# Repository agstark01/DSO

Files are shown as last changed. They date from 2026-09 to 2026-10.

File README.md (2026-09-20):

# DSO
Making a digital oscilloscope for frequency range upto 500khz and voltage range upto +-10V. Sharing the waveforms via pc communication to project it on gui using USB2.0 1MBps speed
## You can see full schematics in [DSO_1draft.pdf](assessment1/DSO_1draft/DSO_1draft.pdf).

## Hardware Subsystems & Circuit Schematics

### 1. Analog Input & Channel Multiplexing
Routes and selects between analog input channels and attenuation paths to direct the conditioned signal toward the sampling stage.

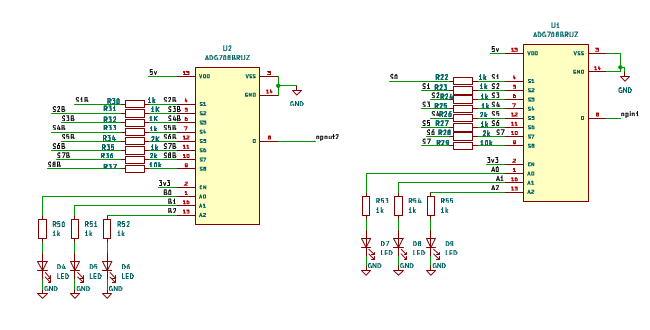
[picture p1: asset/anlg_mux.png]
Analog Multiplexer


---

### 2. Anti-Aliasing Filter
An active low-pass filter stage designed to attenuate high-frequency components above the Nyquist limit, preventing aliasing distortion at the ADC inputs.

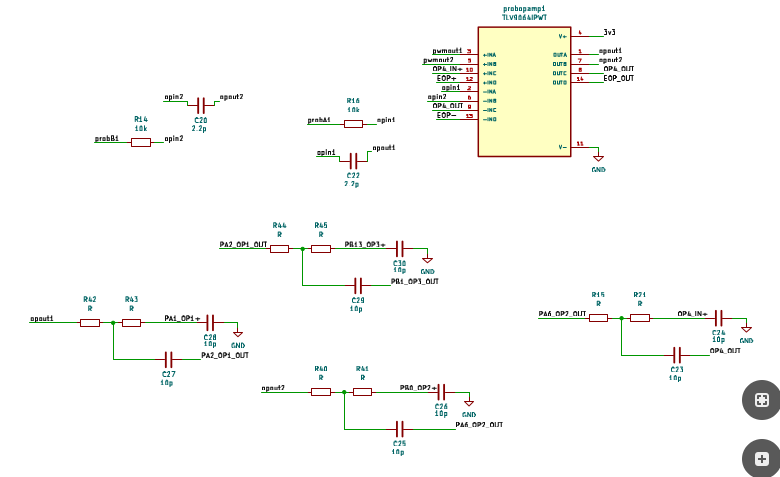
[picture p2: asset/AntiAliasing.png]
Anti-Aliasing Filter


---

### 3. PWM-to-DC Offset Generator
Filters a high-frequency PWM signal from the microcontroller through a low-pass network, producing an adjustable analog DC offset to center and bias bipolar input waveforms within the ADC's 0–3.3V dynamic range.

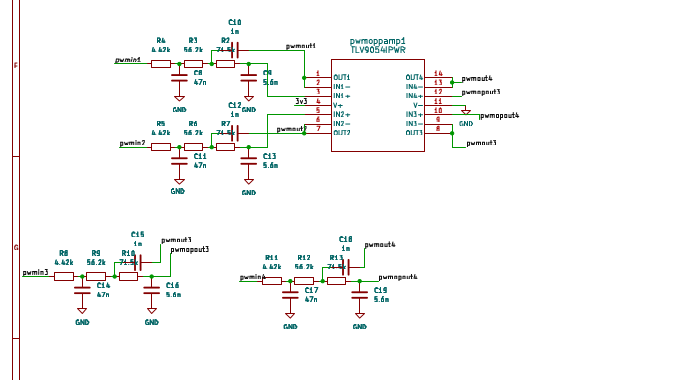
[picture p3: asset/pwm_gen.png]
PWM to DC Offset Stage


---

### 4. Symmetric Dual Supply Generation (±5V)
Generates clean positive (this stage is updated please see pdf) (+5V) and negative (-5V) rails to supply the operational amplifiers, providing the necessary headroom and swing for true bipolar signal conditioning.

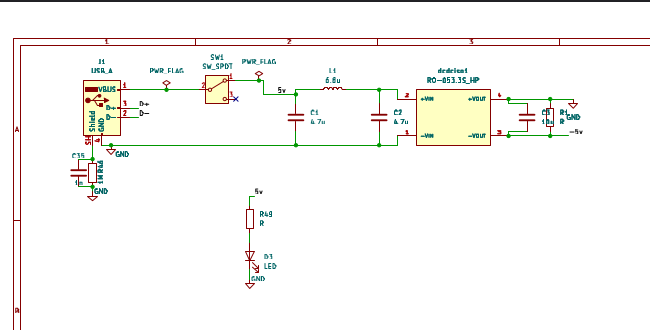
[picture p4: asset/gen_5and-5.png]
±5V Supply Generator


---

### 5. Onboard Function Generator
Generates test signals (e.g., standard 1 kHz square reference or calibration waveforms) for probe compensation, debugging, and self-testing.

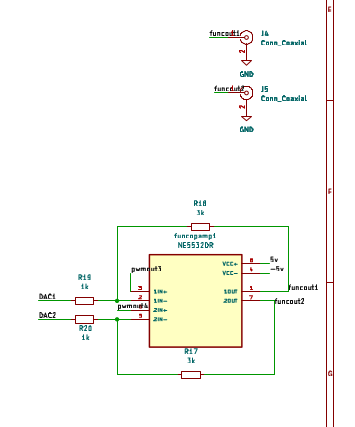
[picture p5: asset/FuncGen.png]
Function Generator


---

### 6. Input Connectors & Channels
Interface connectors (BNC/header pins) for Channel 1 and Channel 2, providing signal entry, grounding, and initial protection.

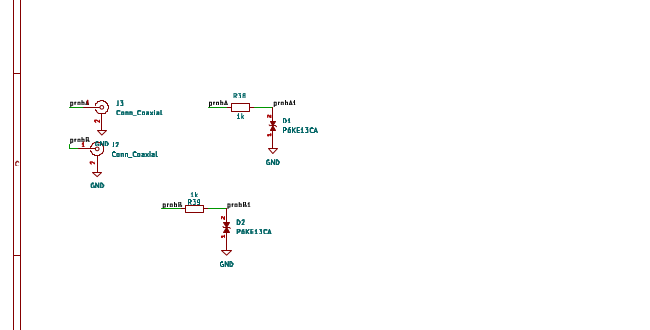
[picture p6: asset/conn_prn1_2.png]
Input Connectors


---

### 7. MCU Programming & Debug Header
Breakout interface (SWD/JTAG and UART/power pins) for flashing firmware to the microcontroller and monitoring real-time telemetry during development.

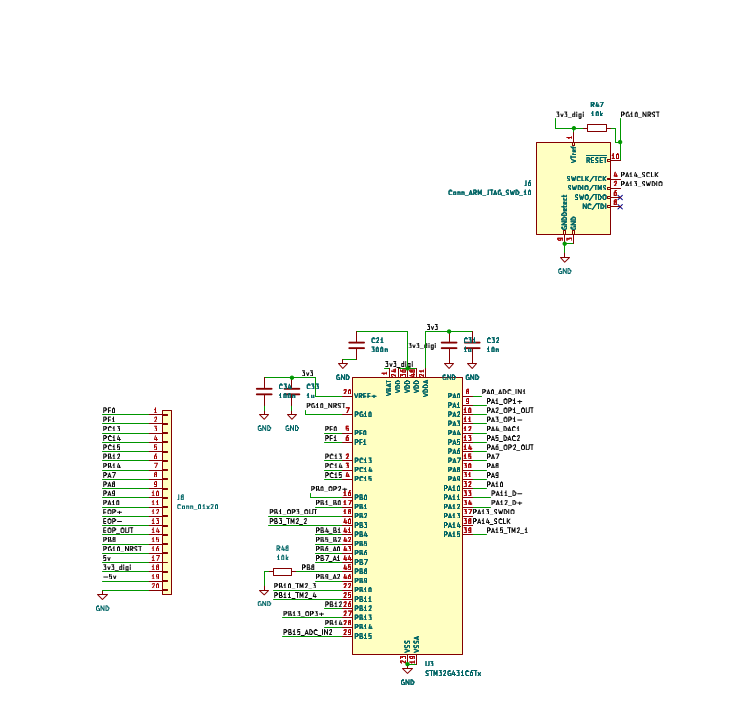
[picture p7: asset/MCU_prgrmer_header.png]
MCU Programmer Header


---

### 8. Net Name & Pin Matching Guide
Reference diagram mapping schematic netlabels, board bus connections, and microcontroller GPIO pinouts across different modules.

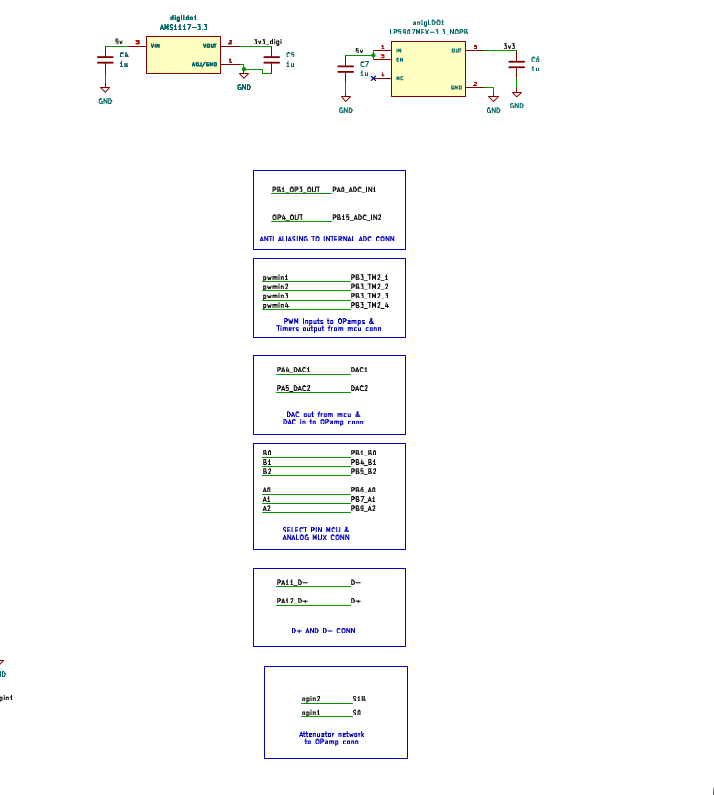
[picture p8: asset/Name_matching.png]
Net Name Matching


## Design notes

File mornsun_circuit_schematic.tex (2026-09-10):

\documentclass[border=20pt]{standalone}
\usepackage[american]{circuitikz}
\begin{document}
\begin{tikzpicture}[scale=1.0, transform shape, thick]

% Power Input
\node[vcc] (vcc_in) at (0,6) {+5V Main};
\node[ground] (gnd_in) at (0,3) {};

% Connect Input
\draw (vcc_in) to[short, -*] (1.5,6) coordinate (in_top);
\draw (gnd_in) to[short, -*] (1.5,3) coordinate (in_bot);
\draw (in_top) to[pC, l=$C_{bulk}$] (in_bot);

% Tap for LDO
\draw (in_top) to[short, -*] (3,6) coordinate (tap_ldo);
\draw (tap_ldo) to[short] (3,8.5) to[short] (4.5,8.5);
\node[draw, minimum width=2.5cm, minimum height=1.5cm, anchor=west] (ldo) at (4.5,8.5) {\shortstack{3.3V LDO\\(e.g., AP7313)}};
\draw (ldo.east) to[short] ++(1.5,0) node[vcc] {3.3V (to DAC)};
\draw (ldo.south) to[short] ++(0,-0.5) node[ground]{};

% Input Filter for DC-DC
\draw (tap_ldo) to[C, l_=$C_1$ $4.7\mu$F, *-*] (3,3);
\draw (3,3) to[short] (in_bot);

\draw (tap_ldo) to[L, l=$L_{DM}$ $6.8\mu$H, -*] (6.5,6) coordinate (dcdc_in);
\draw (3,3) to[short, -*] (6.5,3) coordinate (dcdc_gnd);
\draw (dcdc_in) to[C, l_=$C_2$ $4.7\mu$F, *-*] (dcdc_gnd);

% DC-DC Converter Box
\draw (7.5, 2.5) rectangle (10.5, 6.5);
\node at (9, 4.5) {\shortstack{Mornsun\\B0505S-1WR3}};
\node[anchor=west] at (7.5, 6) {+Vin};
\node[anchor=west] at (7.5, 3) {GND};
\node[anchor=east] at (10.5, 6) {+Vo};
\node[anchor=east] at (10.5, 3) {0V};

\draw (dcdc_in) to[short] (7.5, 6);
\draw (dcdc_gnd) to[short] (7.5, 3);

% Output side
\draw (10.5, 6) to[short, -*] (12, 6) coordinate (vo_plus);
\draw (10.5, 3) to[short, -*] (12, 3) coordinate (vo_minus);

% Grounding +Vo
\draw (vo_plus) to[short] (12, 7.5) node[ground]{System GND};

% Bleeder Resistor
\draw (vo_plus) to[R, l=$R_{bleed}$ $270\Omega$, *-*] (vo_minus);

% Pi Filter on -5V
\draw (vo_minus) to[short, -*] (13.5, 3) coordinate (pi1);
\draw (pi1) to[C, l=$C_3$ $10\mu$F] (13.5, 5) node[ground]{};
\draw (pi1) to[european resistor, l=FB $600\Omega$, -*] (16.5, 3) coordinate (pi2);
\draw (pi2) to[C, l=$C_4$ $10\mu$F+$100$nF] (16.5, 5) node[ground]{};
\draw (pi2) to[short] (18, 3) node[vee] {Clean -5V to Op-Amp};

% Clean 5V Tap for Op-Amp
\draw (tap_ldo) to[short, *-] (3, 0.5) coordinate (op_tap);
\draw (op_tap) to[european resistor, l=FB $600\Omega$, -*] (16.5, 0.5) coordinate (op_vcc);
\draw (op_vcc) to[C, l=$C_{op}$ $10\mu$F+$100$nF] (16.5, -1.5) node[ground]{};
\draw (op_vcc) to[short] (18, 0.5) node[vcc] {Clean +5V to Op-Amp};

\end{tikzpicture}
\end{document}

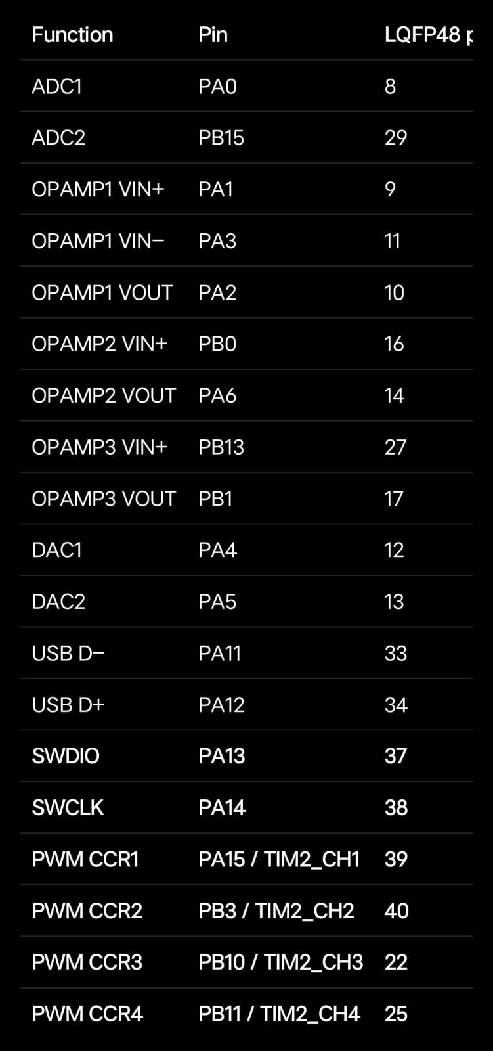
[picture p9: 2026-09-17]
MCUPinConnn.jpeg

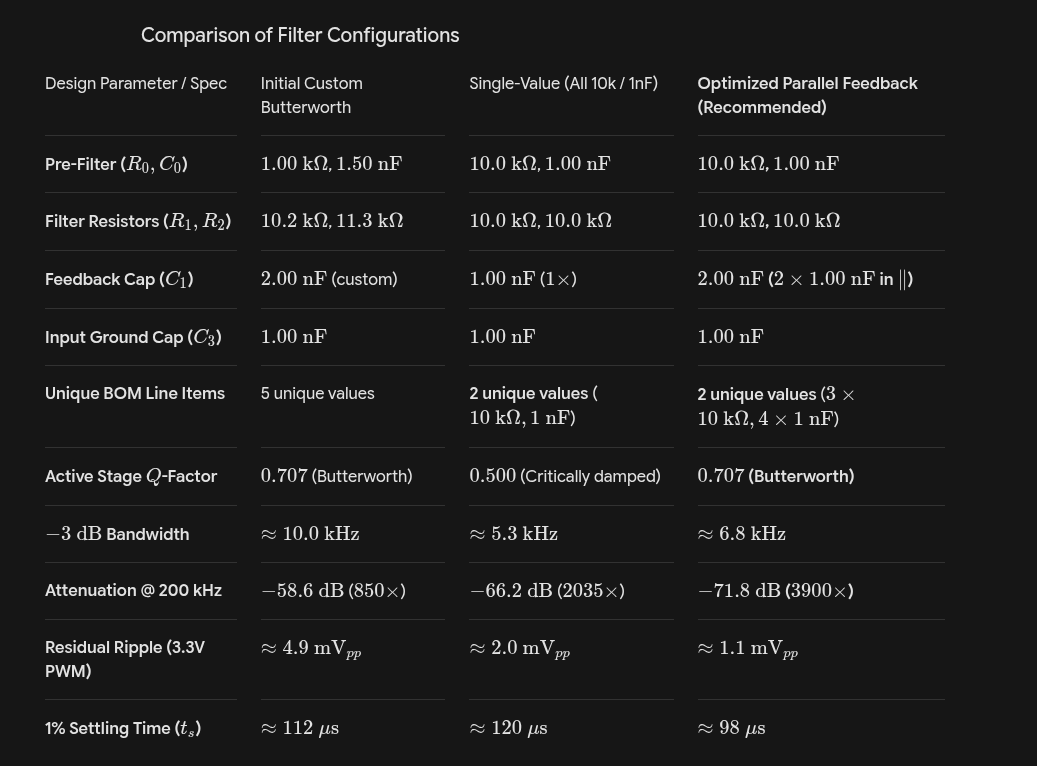
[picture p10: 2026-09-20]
OffsetGen/Pasted image.png

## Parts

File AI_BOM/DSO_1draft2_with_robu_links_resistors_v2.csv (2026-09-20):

Reference | Qty | Value | DNP | Exclude from BOM | Exclude from Board | Exclude from Simulation | Exclude from Position Files | Footprint | Datasheet | Recommended Spec | Robu Purchase Link | Robu Resistor Link | Resistor Alternative
anlgLDO1 | 1 | LP5907MFX-3.3_NOPB |  |  |  |  | ${EXCLUDE_FROM_POS_FILES} | analogLDO:SOT95P280X145-5N
C1,C2 | 2 | 4.7u |  |  |  |  | ${EXCLUDE_FROM_POS_FILES} | Capacitor_SMD:C_1206_3216Metric |  | 10%, X7R, 50 V, 1206 | https://robu.in/product/cl31b475kbhnnne-samsung-electro-mechanics-smd-multilayer-ceramic-capacitor-4-7-%C2%B5f-50-v-1206-pack-of-5/
C3 | 1 | 10u |  |  |  |  | ${EXCLUDE_FROM_POS_FILES} | Capacitor_SMD:C_1206_3216Metric |  | 10%, X7R, 25 V, 1206 | https://robu.in/product/tmk316b7106kl-td-taiyo-yuden-cap-smd-mlcc-10-%C2%B5f-25-v-1206-pack-of-1/
C4,C5,C6,C7,C31,C33 | 6 | 1u |  |  |  |  | ${EXCLUDE_FROM_POS_FILES} | Capacitor_SMD:C_1206_3216Metric |  | 10%, X7R, 25 V, 1206 | https://robu.in/product/c1206c105k3ractu-kemet-smd-multilayer-ceramic-capacitor-1-%C2%B5f-25-v-1206-3216-metric-%C2%B1-10-x7r-c-series-kemet/
C8,C9,C10,C11,C12,C13,C14,C15,C16,C17,C18,C19,C35,C36,C37,C38,C39 | 17 | 1n |  |  |  |  | ${EXCLUDE_FROM_POS_FILES} | Capacitor_SMD:C_1206_3216Metric |  | 1%, C0G/NP0, 50 V, 1206 — Robu exact 1% 1206 listing not found; verify availability | https://robu.in/?s=1nF+1206+C0G+1%25&post_type=product
C20,C22 | 2 | 10p |  |  |  |  | ${EXCLUDE_FROM_POS_FILES} | Capacitor_SMD:C_1206_3216Metric |  | 1%, C0G/NP0, 50 V, 1206 — Robu exact 1% 1206 listing not found; verify availability | https://robu.in/?s=2.2pF+1206+C0G+1%25&post_type=product
C21,C34,C40,C41 | 4 | 100n |  |  |  |  | ${EXCLUDE_FROM_POS_FILES} | Capacitor_SMD:C_1206_3216Metric |  | 10%, X7R, 50 V, 1206 | https://robu.in/?s=1206+100nF+50V+X7R&post_type=product
C23,C29 | 2 | 680p |  |  |  |  | ${EXCLUDE_FROM_POS_FILES} | Capacitor_SMD:C_1206_3216Metric |  | 1%, C0G/NP0, 50 V, 1206 — exact 1% 1206 not found; Robu has 5% 1206 C0G | https://robu.in/product/12065a821jat2a-kyocera-avx-smd-multilayer-ceramic-capacitor-820-pf-50-v-1206-3216-metric-%C2%B1-5-c0g-np0-avx-1206-mlcc/
C24,C25,C26,C27,C28,C30 | 6 | 100p |  |  |  |  | ${EXCLUDE_FROM_POS_FILES} | Capacitor_SMD:C_1206_3216Metric |  | 1%, C0G/NP0, 50 V, 1206 — exact 1% 1206 not found; Robu has 5% 1206 C0G | https://robu.in/product/c1206c101j5gactu-kemet-smd-multilayer-ceramic-capacitor-100-pf-50-v-1206-3216-metric-%C2%B1-5-c0g-np0-c-series-kemet/
C32 | 1 | 10n |  |  |  |  | ${EXCLUDE_FROM_POS_FILES} | Capacitor_SMD:C_1206_3216Metric |  | 1%, C0G/NP0, 50 V, 1206 — Robu exact 1% 1206 listing not found; verify availability | https://robu.in/?s=10nF+1206+C0G+1%25&post_type=product
D1,D2 | 2 | P6KE13CA |  |  |  |  | ${EXCLUDE_FROM_POS_FILES} | TVSdiode:DIOAD1300W80L670D310
D3,D4,D5,D6,D7,D8,D9 | 7 | LED |  |  |  |  | ${EXCLUDE_FROM_POS_FILES} | LED_SMD:LED_1206_3216Metric
dcdciso1 | 1 | RO-053.3S_HP |  |  |  |  | ${EXCLUDE_FROM_POS_FILES} | DCDCisolator:CONV_RO-053.3S_HP
digildo1 | 1 | AMS1117-3.3 |  |  |  |  | ${EXCLUDE_FROM_POS_FILES} | digiLDO:SOT229P700X180-4N
funcopamp1 | 1 | NE5532DR |  |  |  |  | ${EXCLUDE_FROM_POS_FILES} | FuncOPAMP:SOIC127P599X175-8N
J1 | 1 | Conn_01x05 |  |  |  |  | ${EXCLUDE_FROM_POS_FILES} | Connector_PinHeader_2.54mm:PinHeader_1x05_P2.54mm_Vertical
J2,J3,J4,J5 | 4 | Conn_Coaxial |  |  |  |  | ${EXCLUDE_FROM_POS_FILES} | Connector_Coaxial:BNC_Amphenol_B6252HB-NPP3G-50_Horizontal
J7 | 1 | USB_A_Stacked |  |  |  |  | ${EXCLUDE_FROM_POS_FILES} | Connector_USB:USB_A_CUI_UJ2-ADH-TH_Horizontal_Stacked
J8,J9 | 2 | Conn_01x20 |  |  |  |  | ${EXCLUDE_FROM_POS_FILES} | Connector_PinHeader_2.54mm:PinHeader_2x10_P2.54mm_Vertical
L1 | 1 | 6.8u |  |  |  |  | ${EXCLUDE_FROM_POS_FILES} | Inductor_THT:L_Axial_L11.0mm_D4.5mm_P15.24mm_Horizontal_Fastron_MECC
probopamp1 | 1 | TLV9064IPWT |  |  |  |  | ${EXCLUDE_FROM_POS_FILES} | probingopamp:SOP65P640X120-14N
pwmoppamp1 | 1 | TLV9054IPWR |  |  |  |  | ${EXCLUDE_FROM_POS_FILES} | pwmopamp:U_TSSOP_PW_TEX-M | https://www.ti.com/lit/gpn/tlv9054
R1 | 1 | 100 |  |  |  |  | ${EXCLUDE_FROM_POS_FILES} | Resistor_THT:R_Axial_DIN0207_L6.3mm_D2.5mm_P7.62mm_Horizontal |  | 100 Ω, ±1%, THT metal film; keep THT footprint |  | https://robu.in/?s=100+Ohm+0.25W+1%25+Metal+Film+Resistor&post_type=product
R3,R4,R5,R6,R7,R8,R9,R10,R11,R12,R13,R14,R16,R29,R37,R47,R48,R56 | 18 | 10k |  |  |  |  | ${EXCLUDE_FROM_POS_FILES} | Resistor_SMD:R_0805_2012Metric_Pad1.20x1.40mm_HandSolder |  | 10 kΩ, ±1%, 1206, 0.25 W |  | https://robu.in/product/10k-ohm-1-4w-1206-surface-mount-chip-resistor/
R15,R19,R20,R21,R22,R23,R24,R25,R27,R30,R33,R35,R38,R39,R44,R45,R49,R50,R51,R52,R53,R54,R55 | 23 | 1k |  |  |  |  | ${EXCLUDE_FROM_POS_FILES} | Resistor_SMD:R_0805_2012Metric_Pad1.20x1.40mm_HandSolder |  | 1 kΩ, ±1%, 1206, 0.25 W |  | https://robu.in/product/rc1206fr-071kl-yageo-res-thick-film-1206-1k-ohm-1-0-25w1-4w-%C2%B1100ppm-c-pad-smd-t-r/
R17,R18 | 2 | 3k |  |  |  |  | ${EXCLUDE_FROM_POS_FILES} | Resistor_SMD:R_0805_2012Metric_Pad1.20x1.40mm_HandSolder |  | 3.01 kΩ, ±1%, 1206, 0.25 W — near substitute for 3 kΩ (+0.33%) |  | https://robu.in/product/ac1206fr-073k01l-yageo-250mw-3-01k%CF%89-thick-film-200v-%C2%B11-%C2%B1100ppm-%E2%84%83-1206-chip-resistor-surface-mount-rohs/ | 3.01 kΩ
R26,R28,R36,R40,R41,R42,R43 | 7 | 2.2k |  |  |  |  | ${EXCLUDE_FROM_POS_FILES} | Resistor_SMD:R_0805_2012Metric_Pad1.20x1.40mm_HandSolder |  | 2.00 kΩ, ±1%, 1206 preferred; Robu exact listing not verified |  | https://robu.in/?s=2k+1206+1%25+resistor&post_type=product | 2.05 kΩ is the next practical E96-style near-value to check if 2.00 kΩ is unavailable
R31,R32 | 2 | 1K |  |  |  |  | ${EXCLUDE_FROM_POS_FILES} | Resistor_SMD:R_0805_2012Metric_Pad1.20x1.40mm_HandSolder |  | 1 kΩ, ±1%, 1206, 0.25 W |  | https://robu.in/product/rc1206fr-071kl-yageo-res-thick-film-1206-1k-ohm-1-0-25w1-4w-%C2%B1100ppm-c-pad-smd-t-r/
R34 | 1 | 2.2k |  |  |  |  | ${EXCLUDE_FROM_POS_FILES} | Resistor_SMD:R_0805_2012Metric_Pad1.20x1.40mm_HandSolder |  | 2.00 kΩ, ±1%, 1206 preferred; same as 2 kΩ group |  | https://robu.in/?s=2k+1206+1%25+resistor&post_type=product | 2.05 kΩ near alternative to check if exact 2.00 kΩ is unavailable
R46 | 1 | 1M |  |  |  |  | ${EXCLUDE_FROM_POS_FILES} | Resistor_THT:R_Axial_DIN0207_L6.3mm_D2.5mm_P7.62mm_Horizontal |  | 1 MΩ, ±1%, 0.25 W; THT as currently specified |  | https://robu.in/?s=1M+Ohm+0.25W+1%25+Metal+Film+Resistor&post_type=product
SW1,SW2 | 2 | SW_SPDT |  |  |  |  | ${EXCLUDE_FROM_POS_FILES} | Slide_switch:SS-12F17_1P2T
U1,U2 | 2 | ADG708BRUZ |  |  |  |  | ${EXCLUDE_FROM_POS_FILES} | Analog_mux:TSSOP16
U3 | 1 | STM32G431C6Tx |  |  |  |  | ${EXCLUDE_FROM_POS_FILES} | Package_QFP:LQFP-48_7x7mm_P0.5mm | https://www.st.com/resource/en/datasheet/stm32g431c6.pdf

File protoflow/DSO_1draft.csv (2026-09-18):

Reference | Qty | Value | DNP | Exclude from BOM | Exclude from Board | Exclude from Simulation | Exclude from Position Files | Footprint | Datasheet
anlgLDO1 | 1 | LP5907MFX-3.3_NOPB |  |  |  |  | ${EXCLUDE_FROM_POS_FILES} | LP5907MFX-3.3_NOPB:SOT95P280X145-5N
C1,C2 | 2 | 4.7u |  |  |  |  | ${EXCLUDE_FROM_POS_FILES}
C3 | 1 | 10u |  |  |  |  | ${EXCLUDE_FROM_POS_FILES}
C4,C5,C6,C7,C31,C33 | 6 | 1u |  |  |  |  | ${EXCLUDE_FROM_POS_FILES}
C8,C11,C14,C17 | 4 | 47n |  |  |  |  | ${EXCLUDE_FROM_POS_FILES}
C9,C13,C16,C19 | 4 | 5.6n |  |  |  |  | ${EXCLUDE_FROM_POS_FILES}
C10,C12,C15,C18,C35 | 5 | 1n |  |  |  |  | ${EXCLUDE_FROM_POS_FILES}
C20,C22 | 2 | 2.2p |  |  |  |  | ${EXCLUDE_FROM_POS_FILES}
C21 | 1 | 300n |  |  |  |  | ${EXCLUDE_FROM_POS_FILES}
C23,C24,C25,C26,C27,C28,C29,C30 | 8 | 10p |  |  |  |  | ${EXCLUDE_FROM_POS_FILES}
C32 | 1 | 10n |  |  |  |  | ${EXCLUDE_FROM_POS_FILES}
C34 | 1 | 100n |  |  |  |  | ${EXCLUDE_FROM_POS_FILES}
D1,D2 | 2 | P6KE13CA |  |  |  |  | ${EXCLUDE_FROM_POS_FILES} | P6KE13CA:DIOAD1300W80L670D310
D3,D4,D5,D6,D7,D8,D9 | 7 | LED |  |  |  |  | ${EXCLUDE_FROM_POS_FILES}
dcdciso1 | 1 | RO-053.3S_HP |  |  |  |  | ${EXCLUDE_FROM_POS_FILES} | RO-053.3S_HP:CONV_RO-053.3S_HP
digildo1 | 1 | AMS1117-3.3 |  |  |  |  | ${EXCLUDE_FROM_POS_FILES} | AMS1117-3.3:SOT229P700X180-4N
funcopamp1 | 1 | NE5532DR |  |  |  |  | ${EXCLUDE_FROM_POS_FILES} | NE5532DR:SOIC127P599X175-8N
J1 | 1 | USB_A , sym and ftprnt have to chg to double usb |  |  |  |  | ${EXCLUDE_FROM_POS_FILES}
J2,J3,J4,J5 | 4 | Conn_Coaxial (shriniwas comp) |  |  |  |  | ${EXCLUDE_FROM_POS_FILES}
J6 | 1 | Conn_ARM_JTAG_SWD_10 |  |  |  |  | ${EXCLUDE_FROM_POS_FILES} |  | http://infocenter.arm.com/help/topic/com.arm.doc.ddi0314h/DDI0314H_coresight_components_trm.pdf
J8 | 1 | Conn_01x20 |  |  |  |  | ${EXCLUDE_FROM_POS_FILES}
L1 | 1 | 6.8u |  |  |  |  | ${EXCLUDE_FROM_POS_FILES}
probopamp1 | 1 | TLV9064IPWT |  |  |  |  | ${EXCLUDE_FROM_POS_FILES} | TLV9064IPWT:SOP65P640X120-14N
pwmoppamp1 | 1 | TLV9054IPWR |  |  |  |  | ${EXCLUDE_FROM_POS_FILES} | U_TSSOP_PW_TEX | https://www.ti.com/lit/gpn/tlv9054
R1,R15,R21,R40,R41,R42,R43,R44,R45,R49 | 10 | R |  |  |  |  | ${EXCLUDE_FROM_POS_FILES}
R2,R7,R10,R13 | 4 | 71.5k |  |  |  |  | ${EXCLUDE_FROM_POS_FILES}
R3,R6,R9,R12 | 4 | 56.2k |  |  |  |  | ${EXCLUDE_FROM_POS_FILES}
R4,R5,R8,R11 | 4 | 4.42k |  |  |  |  | ${EXCLUDE_FROM_POS_FILES}
R14,R16,R29,R37,R47,R48 | 6 | 10k |  |  |  |  | ${EXCLUDE_FROM_POS_FILES}
R17,R18 | 2 | 3k |  |  |  |  | ${EXCLUDE_FROM_POS_FILES}
R19,R20,R22,R23,R24,R25,R27,R30,R33,R35,R38,R39,R50,R51,R52,R53,R54,R55 | 18 | 1k |  |  |  |  | ${EXCLUDE_FROM_POS_FILES}
R26,R28,R36 | 3 | 2k |  |  |  |  | ${EXCLUDE_FROM_POS_FILES}
R31,R32 | 2 | 1K |  |  |  |  | ${EXCLUDE_FROM_POS_FILES}
R34 | 1 | 2K |  |  |  |  | ${EXCLUDE_FROM_POS_FILES}
R46 | 1 | 1M |  |  |  |  | ${EXCLUDE_FROM_POS_FILES}
SW1 | 1 | SW_SPDT |  |  |  |  | ${EXCLUDE_FROM_POS_FILES}
U1,U2 | 2 | ADG708BRUZ |  |  |  |  | ${EXCLUDE_FROM_POS_FILES} | ADG708BRUZ:TSSOP16
U3 | 2 | STM32G431C6Tx |  |  |  |  | ${EXCLUDE_FROM_POS_FILES} | Package_QFP:LQFP-48_7x7mm_P0.5mm | https://www.st.com/resource/en/datasheet/stm32g431c6.pdf

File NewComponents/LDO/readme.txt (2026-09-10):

# making this folder for saving all the digital and analog LDO files

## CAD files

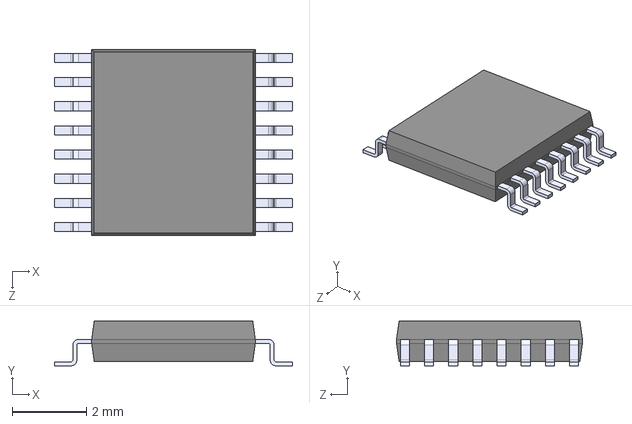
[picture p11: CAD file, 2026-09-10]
NewComponents/Analog_MUX/ADG708BRUZ/ADG708BRUZ.step
6.40 x 1.20 x 5.00 mm

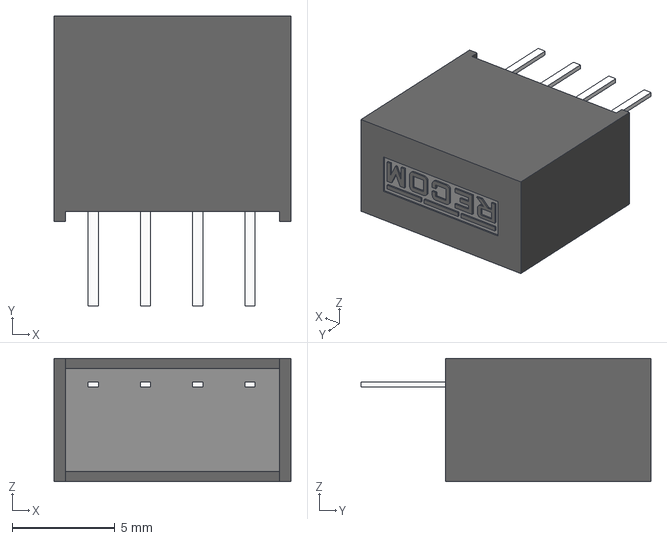
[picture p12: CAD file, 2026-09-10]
NewComponents/charge_pump/isolated/RO-053.3S_HP/RO-053.3S_HP.step
11.5 x 14.1 x 6.00 mm

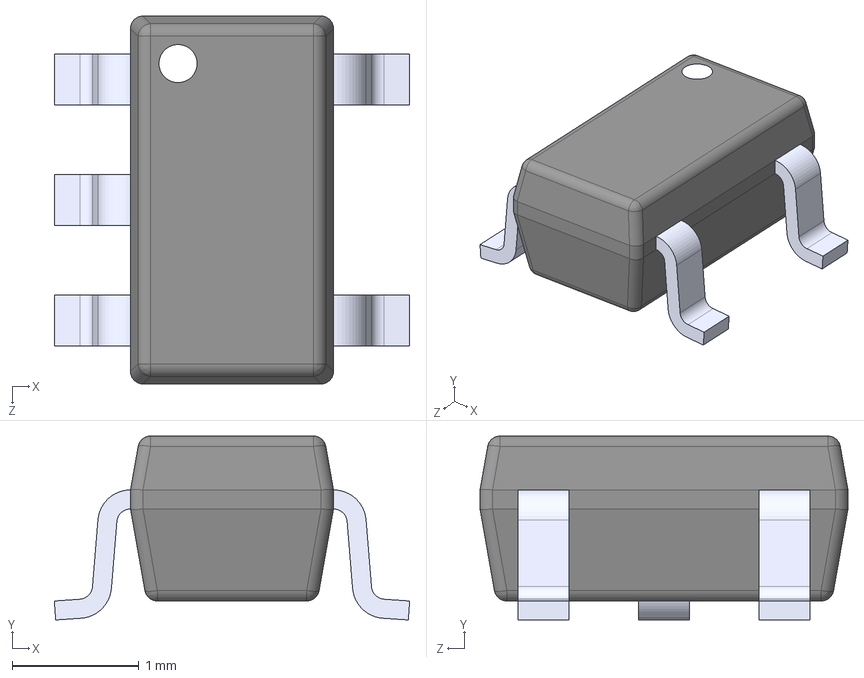
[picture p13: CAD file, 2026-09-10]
NewComponents/LDO/Analog LDO/LP5907MFX-3.3_NOPB/LP5907MFX-3.3_NOPB.step
2.80 x 1.45 x 2.90 mm

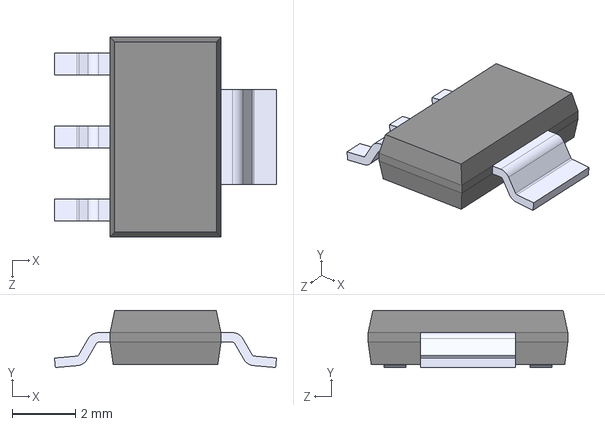
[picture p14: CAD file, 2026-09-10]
NewComponents/LDO/Digital LDO/AMS1117-3.3/AMS1117-3.3.step
7.00 x 1.80 x 6.30 mm

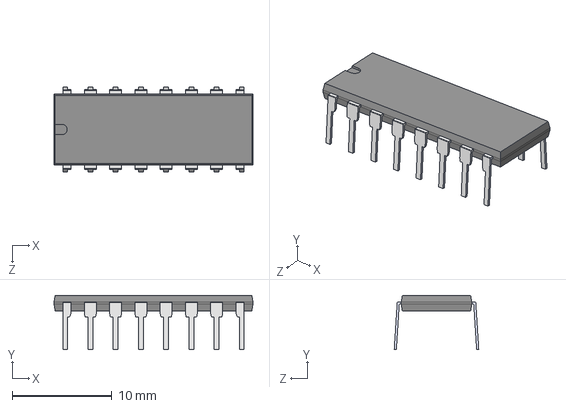
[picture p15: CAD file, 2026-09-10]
NewComponents/LIB_HCF4051BE/HCF4051BE/3D/HCF4051BE.stp
20.0 x 5.45 x 8.50 mm

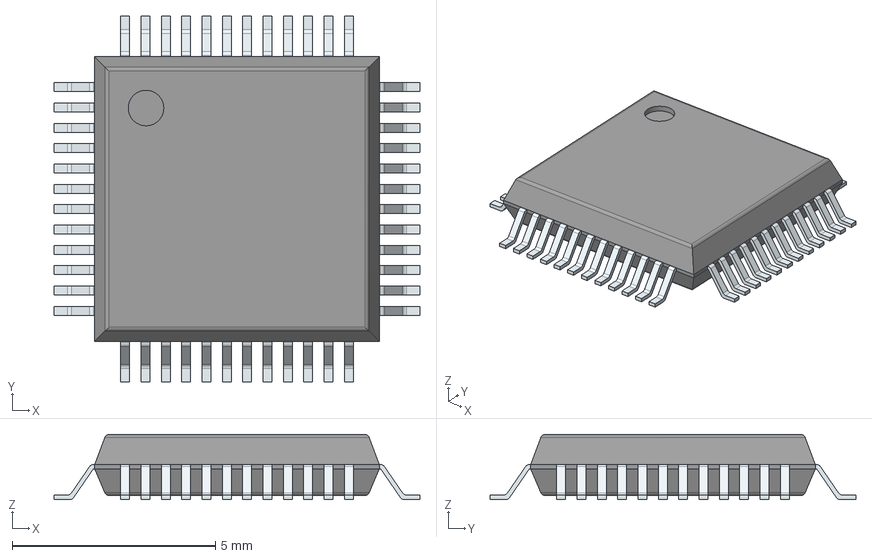
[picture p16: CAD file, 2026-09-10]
NewComponents/LIB_STM32G431C6T6/STM32G431C6T6/3D/STM32G431C6T6.stp
9.00 x 9.00 x 1.60 mm
PinsArrayLR
PinsArrayTB

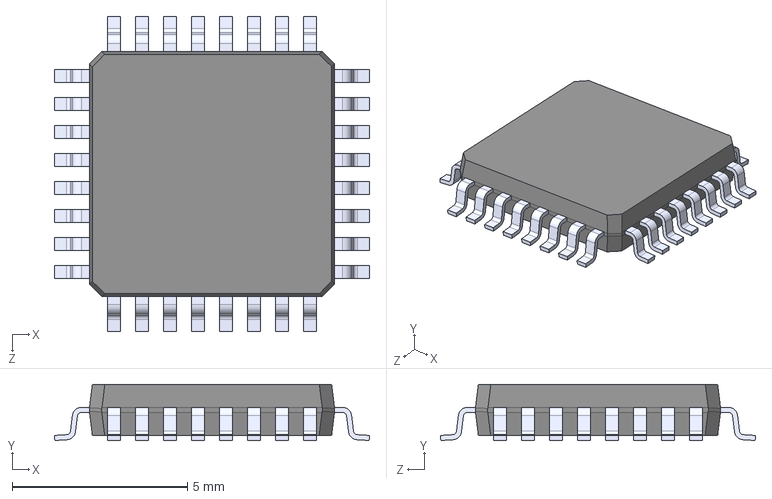
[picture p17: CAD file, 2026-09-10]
NewComponents/MCU/STM32G431KBT6/STM32G431KBT6.step
9.00 x 1.60 x 9.00 mm

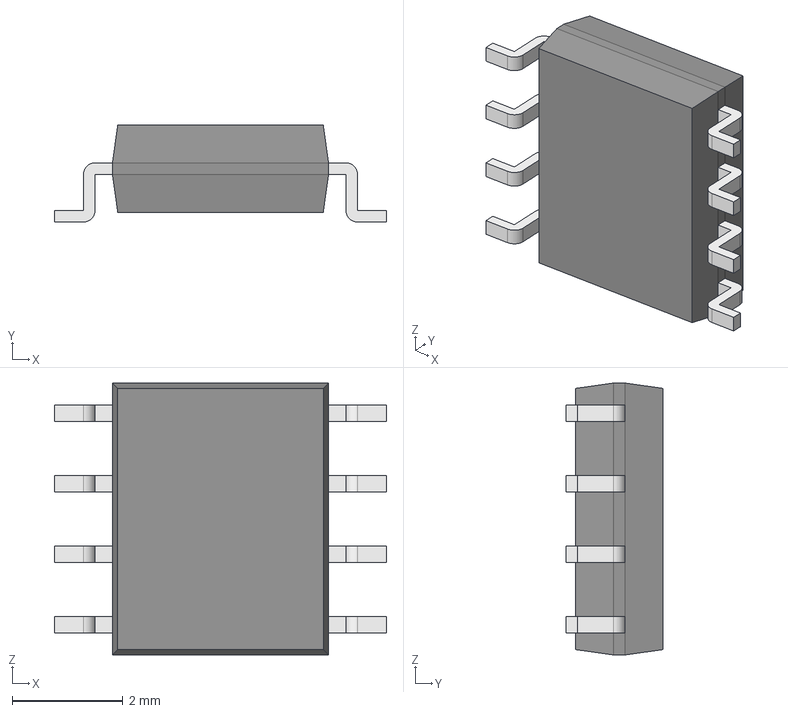
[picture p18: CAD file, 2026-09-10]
NewComponents/quad_oamp/latest_funcgen/NE5532DR/NE5532DR.step
5.99 x 1.75 x 4.91 mm
Body001 (Mirror #1) x 4
XY-plane x 12
X-axis x 12

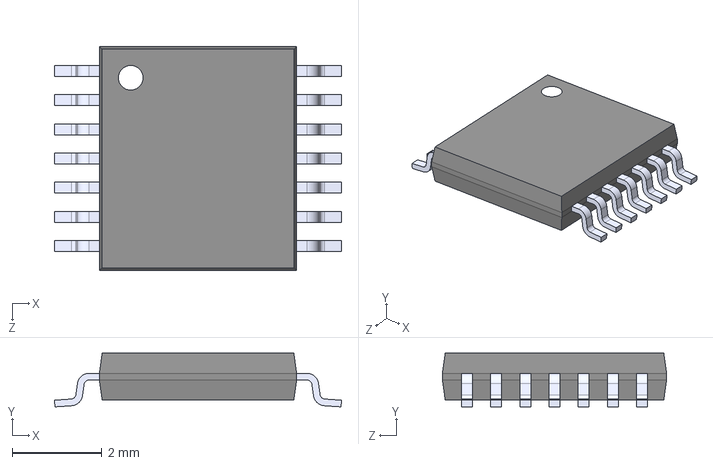
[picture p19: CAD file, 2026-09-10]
NewComponents/quad_oamp/latest_probingpath/TLV9064IPWT/TLV9064IPWT.step
6.40 x 1.20 x 5.00 mm

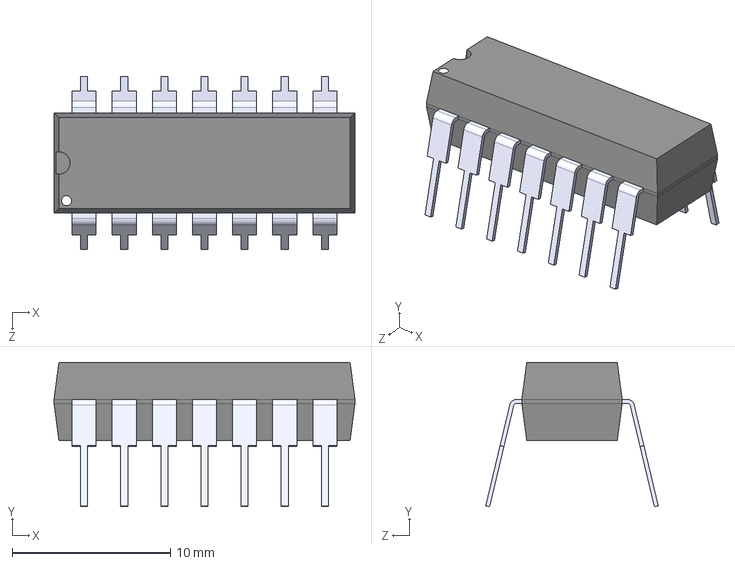
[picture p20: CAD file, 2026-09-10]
NewComponents/quad_oamp/MCP6024-I_P/MCP6024-I_P.step
19.1 x 9.14 x 10.9 mm

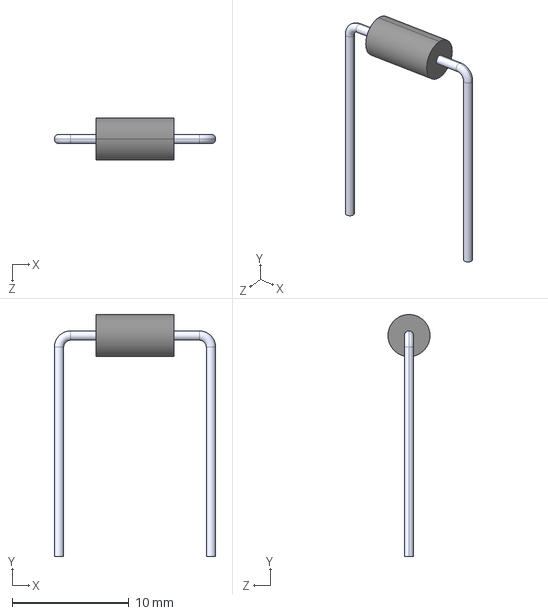
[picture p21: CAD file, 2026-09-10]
NewComponents/TVS/P6KE13CA/P6KE13CA.step
13.8 x 20.7 x 3.60 mm

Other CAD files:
NewComponents/LIB_HCF4051BE/HCF4051BE/Allegro/dip850w50p254l2000h510q16n.psm
NewComponents/LIB_HCF4051BE/HCF4051BE/DEHDL/hcf4051be/chips/chips.prt
NewComponents/LIB_STM32G431C6T6/STM32G431C6T6/Allegro/qfp50p900x900x160-48n.psm
NewComponents/LIB_STM32G431C6T6/STM32G431C6T6/DEHDL/stm32g431c6t6/chips/chips.prt

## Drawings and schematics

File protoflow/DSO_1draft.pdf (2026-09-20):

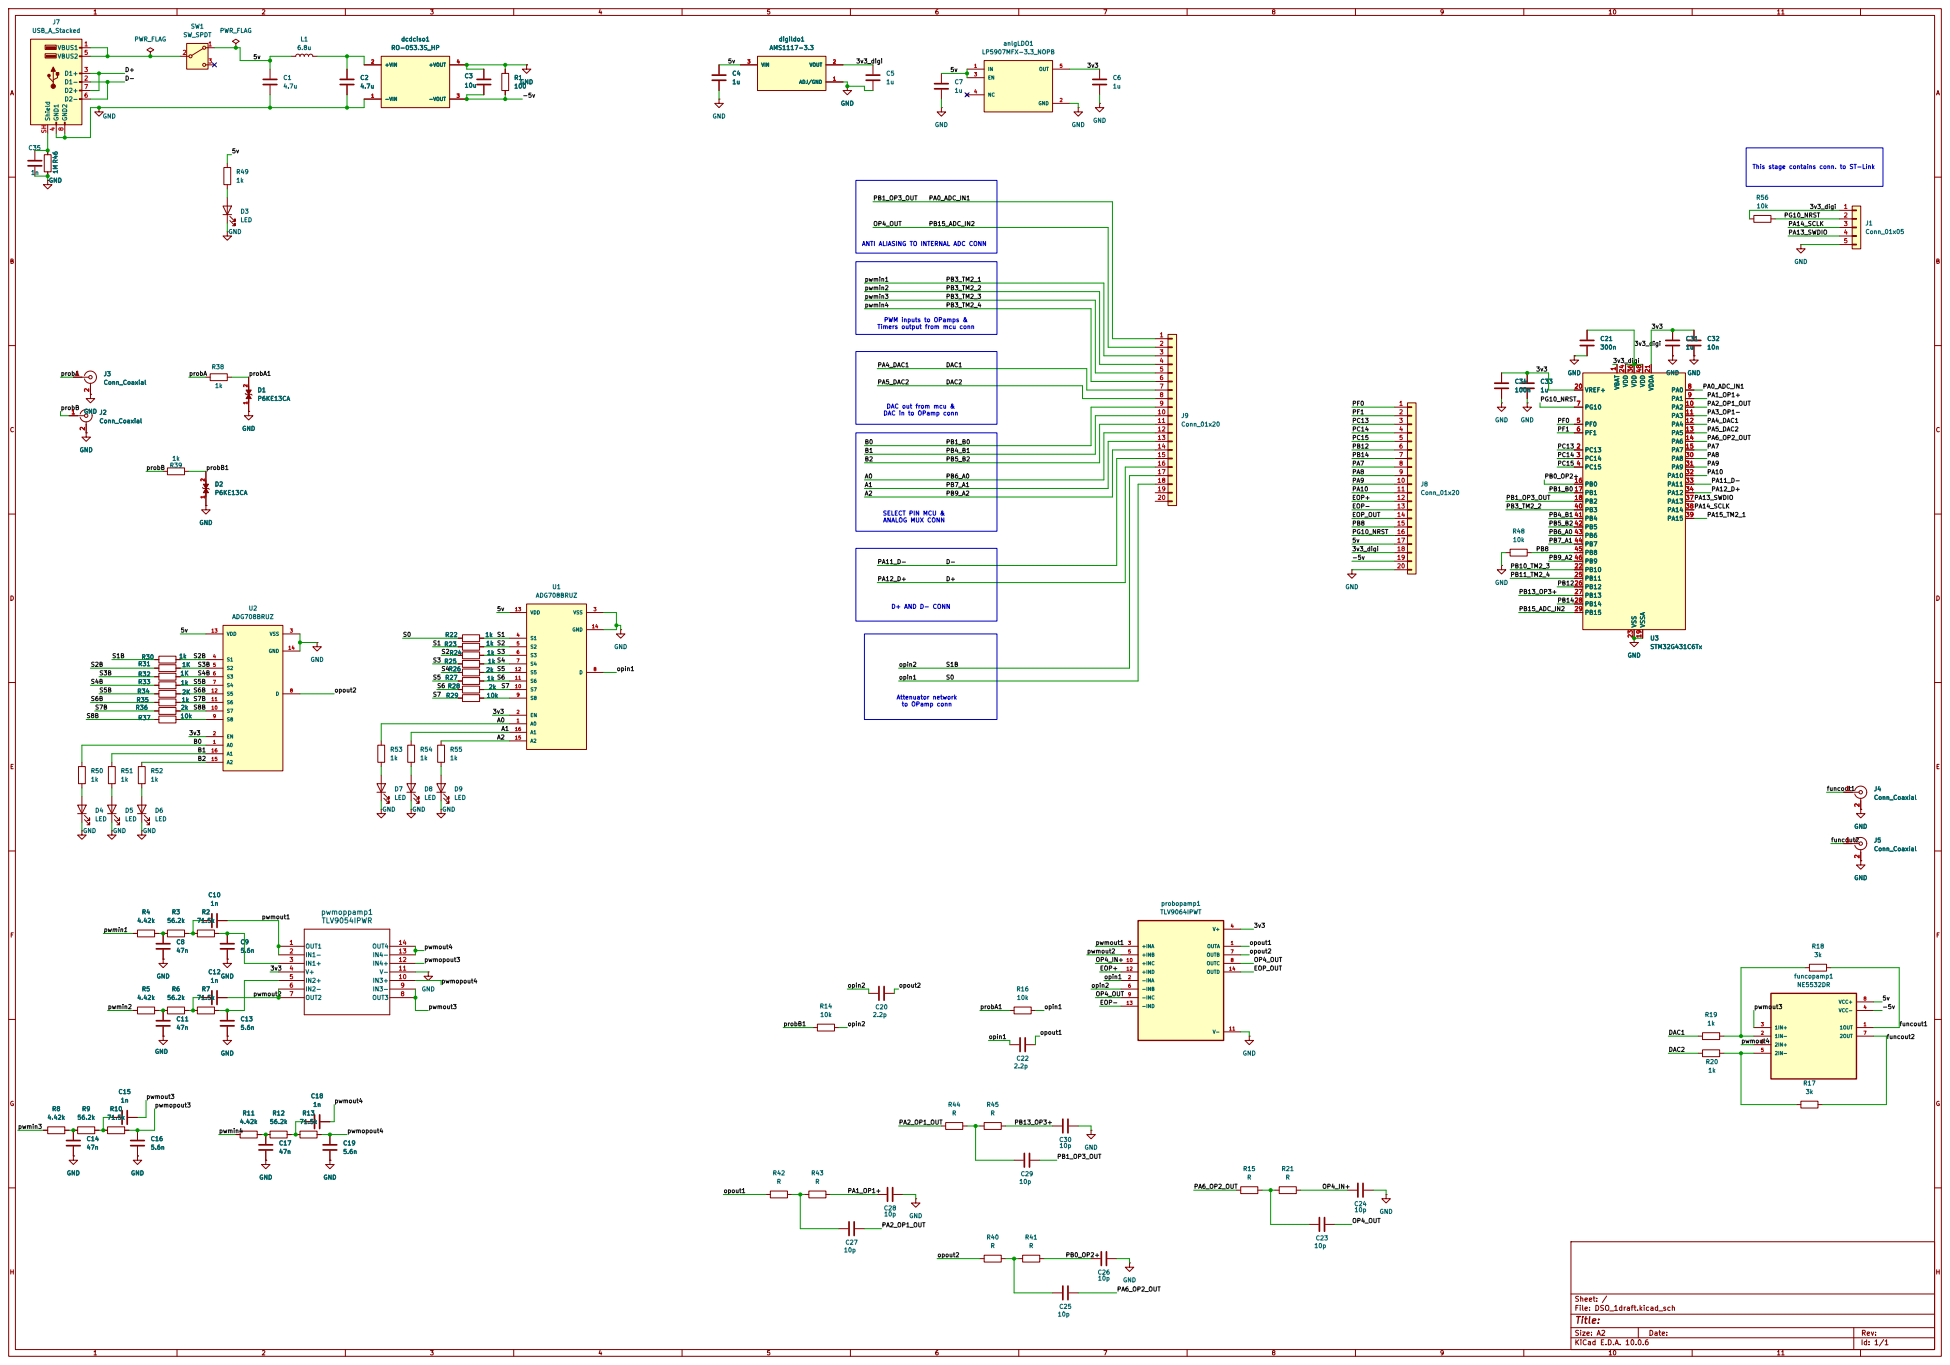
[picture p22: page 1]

This stage contains conn. to ST-Link D+ AND D- CONN

ANTI ALIASING TO INTERNAL ADC CONN

PB9_A2 PB7_A1 PWM inputs to OPamps &
Timers output from mcu conn
PB6_A0 PB5_B2 PB1_B0 PB4_B1 PB7_A1 PB9_A2 DAC1 D+

DAC out from mcu &
DAC in to OPamp conn

Size: A2 | Rev:
KiCad E.D.A. 10.0.6 | Id: 1/1

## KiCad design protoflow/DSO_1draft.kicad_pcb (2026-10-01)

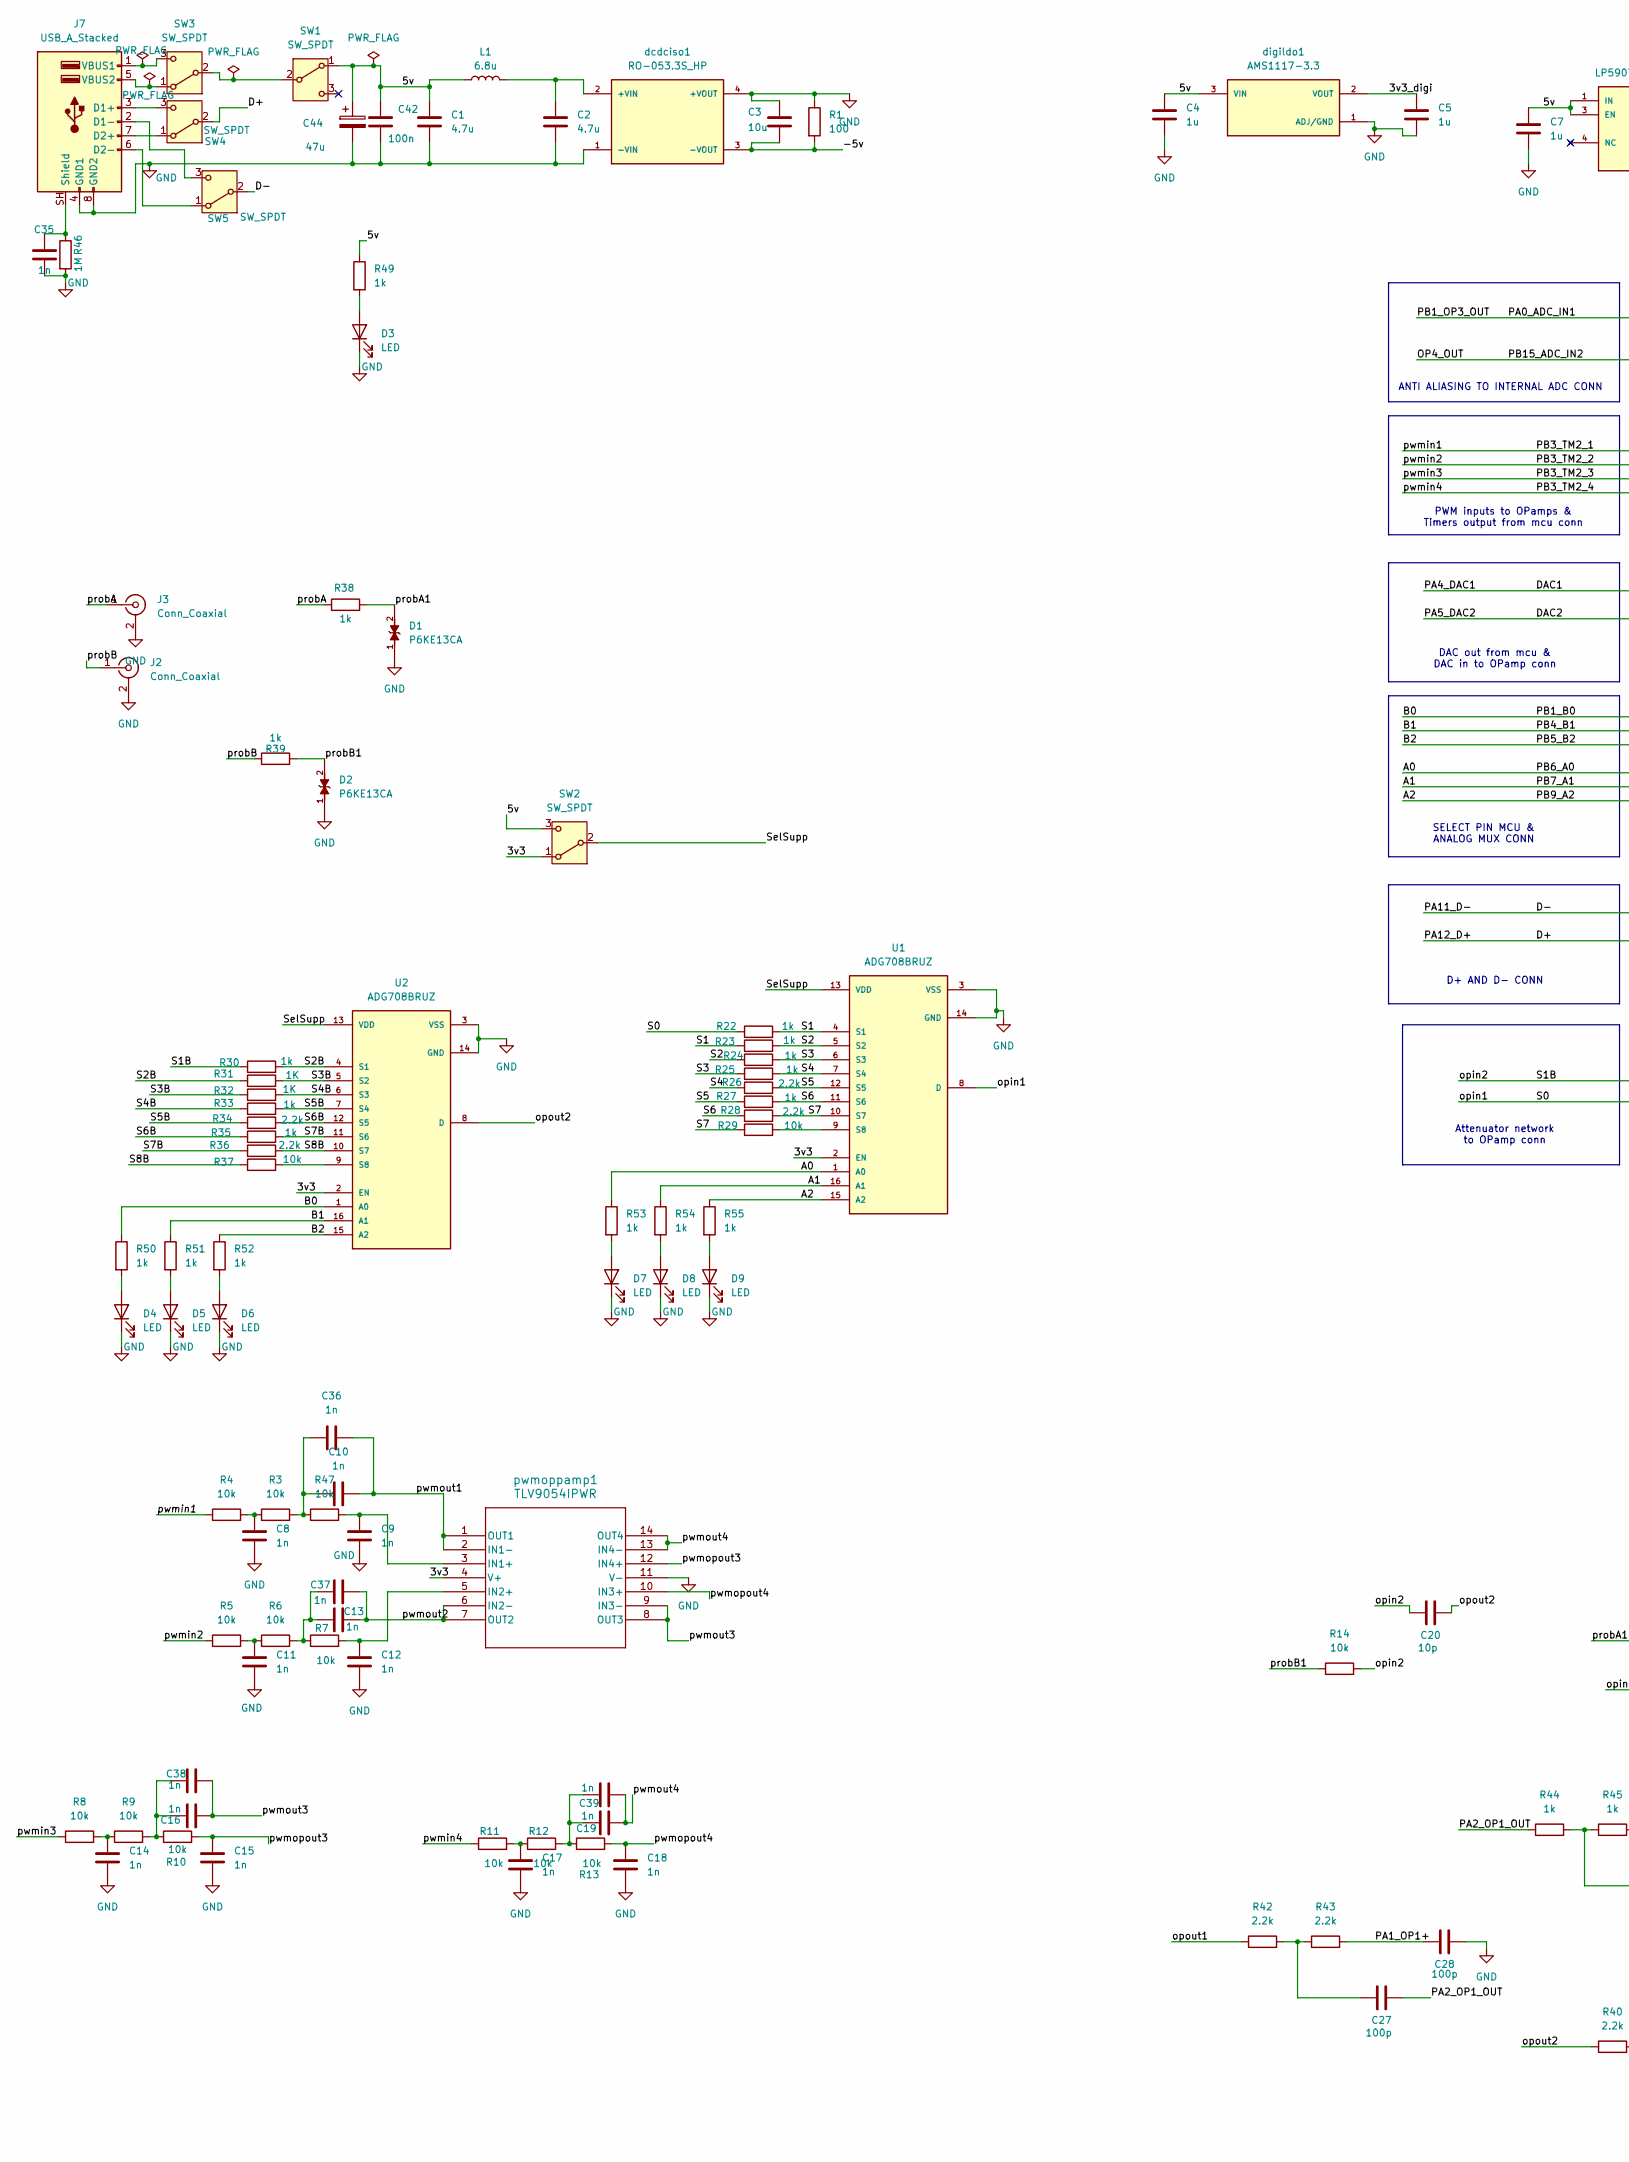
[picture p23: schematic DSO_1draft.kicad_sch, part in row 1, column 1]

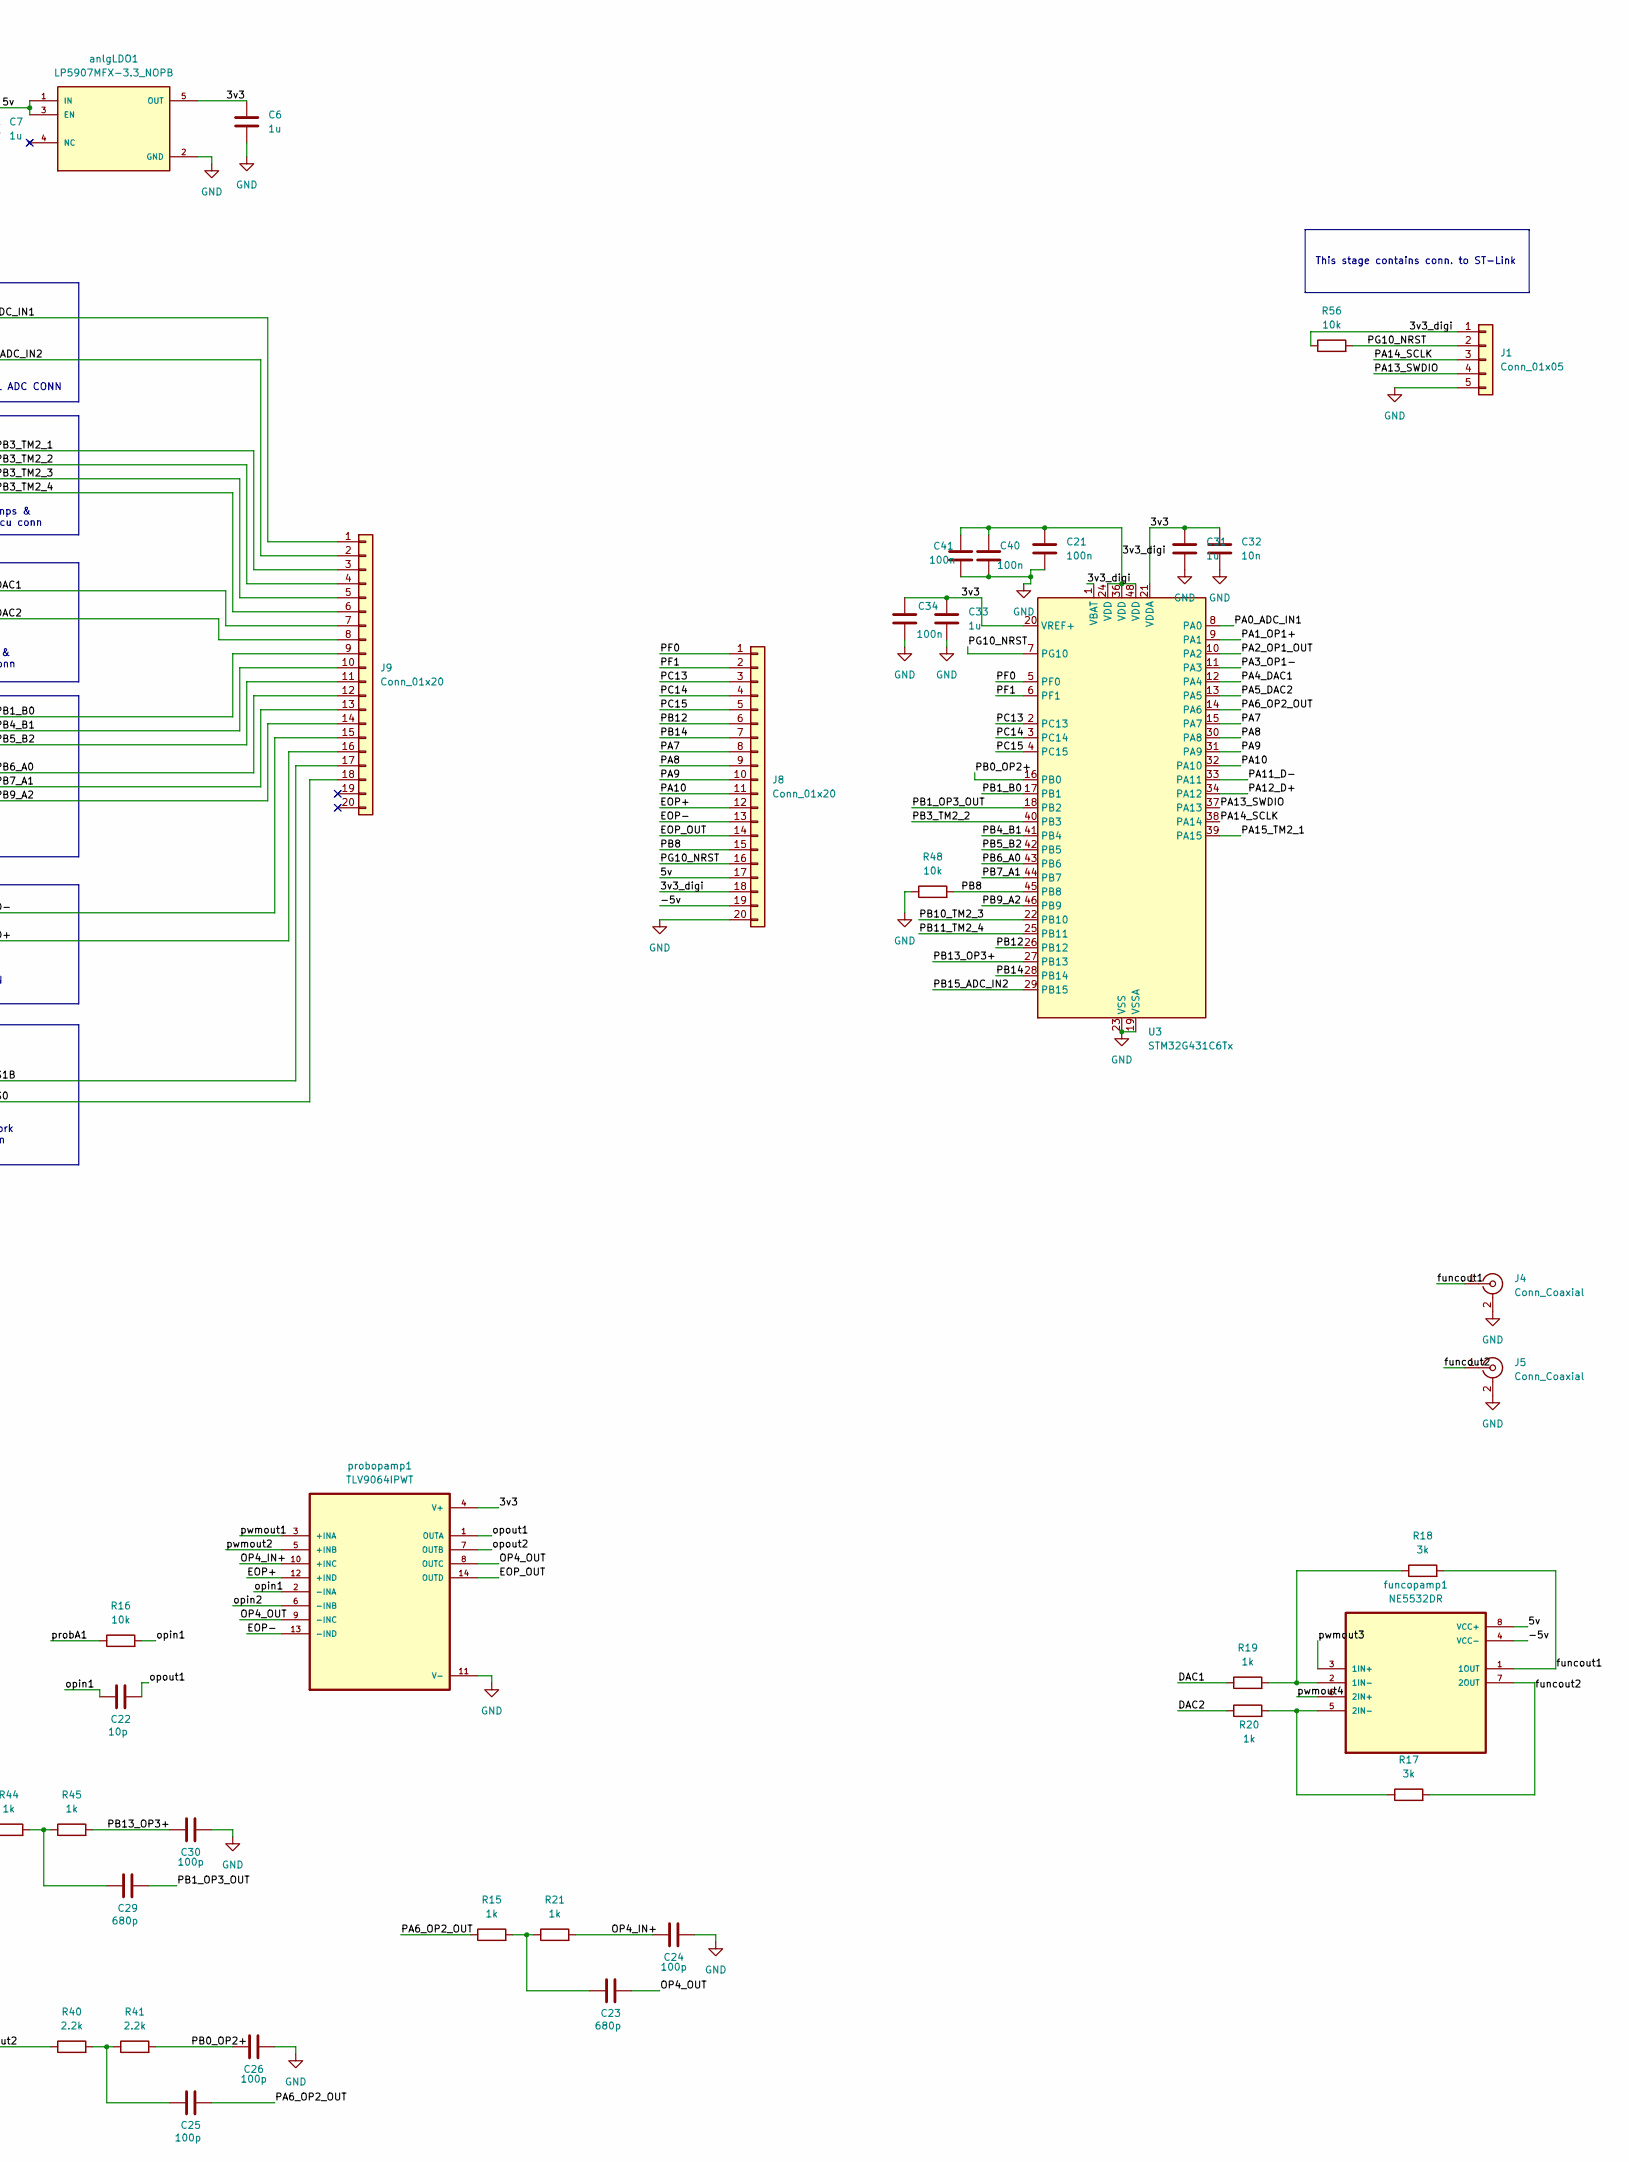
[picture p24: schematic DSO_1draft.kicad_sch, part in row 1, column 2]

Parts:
C1, C2: 4.7u; C_1206_3216Metric_Pad1.33x1.80mm_HandSolder
C3: 10u; C_1206_3216Metric_Pad1.33x1.80mm_HandSolder
C4, C5, C6, C7, C31, C33: 1u; C_1206_3216Metric_Pad1.33x1.80mm_HandSolder
C8, C9, C10, C11, C12, C13, C14, C15, C16, C17, C18, C19, C35, C36, C37, C38, C39: 1n; C_1206_3216Metric_Pad1.33x1.80mm_HandSolder
C20, C22: 10p; C_1206_3216Metric_Pad1.33x1.80mm_HandSolder
C21, C34, C40, C41, C42: 100n; C_1206_3216Metric_Pad1.33x1.80mm_HandSolder
C23, C29: 680p; C_1206_3216Metric_Pad1.33x1.80mm_HandSolder
C24, C25, C26, C27, C28, C30: 100p; C_1206_3216Metric_Pad1.33x1.80mm_HandSolder
C32: 10n; C_1206_3216Metric_Pad1.33x1.80mm_HandSolder
C44: 47u; C_Radial_D5.0mm_H11.0mm_P2.00mm
D1, D2: P6KE13CA; DIOAD1300W80L670D310; PARTREV O2109
D3, D4, D5, D6, D7, D8, D9: LED; LED_1206_3216Metric
J1: Conn_01x05; PinHeader_1x05_P2.54mm_Vertical
J2, J3, J4, J5: Conn_Coaxial; BNC_Amphenol_B6252HB-NPP3G-50_Horizontal
J7: USB_A_Stacked; USB_A_CUI_UJ2-ADH-TH_Horizontal_Stacked
J8, J9: Conn_01x20; PinHeader_2x10_P2.54mm_Vertical
L1: 6.8u; L_Axial_L11.0mm_D4.5mm_P15.24mm_Horizontal_Fastron_MECC
R1: 100; R_Axial_DIN0207_L6.3mm_D2.5mm_P7.62mm_Horizontal
R3, R4, R5, R6, R7, R8, R9, R10, R11, R12, R13, R14, R16, R29, R37, R47, R48, R56: 10k; R_1206_3216Metric_Pad1.30x1.75mm_HandSolder
R15, R19, R20, R21, R22, R23, R24, R25, R27, R30, R33, R35, R38, R39, R44, R45, R49, R50, R51, R52, R53, R54, R55: 1k; R_1206_3216Metric_Pad1.30x1.75mm_HandSolder
R17, R18: 3k; R_1206_3216Metric_Pad1.30x1.75mm_HandSolder
R26, R28, R34, R36, R40, R41, R42, R43: 2.2k; R_1206_3216Metric_Pad1.30x1.75mm_HandSolder
R31, R32: 1K; R_1206_3216Metric_Pad1.30x1.75mm_HandSolder
R46: 1M; R_Axial_DIN0207_L6.3mm_D2.5mm_P7.62mm_Horizontal
SW1, SW2, SW3, SW4, SW5: SW_SPDT; SS-12F17_1P2T
U1, U2: ADG708BRUZ; TSSOP16
U3: STM32G431C6Tx; LQFP-48_7x7mm_P0.5mm
anlgLDO1: LP5907MFX-3.3_NOPB; SOT95P280X145-5N; PARTREV Q
dcdciso1: RO-053.3S_HP; CONV_RO-053.3S_HP; PARTREV 3
digildo1: AMS1117-3.3; SOT229P700X180-4N; PARTREV NA
funcopamp1: NE5532DR; SOIC127P599X175-8N
probopamp1: TLV9064IPWT; SOP65P640X120-14N
pwmoppamp1: TLV9054IPWR; U_TSSOP_PW_TEX-M

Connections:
/3v3: C6.1, C31.1, C32.1, C33.1, C34.1, SW2.1 (A), U1.2 (EN), U2.2 (EN), U3.20 (VREF+), U3.21 (VDDA), anlgLDO1.5 (OUT), probopamp1.4 (V+), pwmoppamp1.4 (V+)
/3v3_digi: C5.1, C21.1, C40.1, C41.1, J1.1, J8.18, R56.1, U3.1 (VBAT), U3.24 (VDD), U3.36 (VDD), U3.48 (VDD), digildo1.2 (VOUT)
/5v: C1.1, C4.1, C7.1, C42.1, C44.1, J8.17, L1.1, R49.1, SW1.1 (A), SW2.3 (C), anlgLDO1.1 (IN), anlgLDO1.3 (EN), digildo1.3 (VIN), funcopamp1.8 (VCC+)
/-5v: C3.2, J8.19, R1.2, dcdciso1.3 (-VOUT), funcopamp1.4 (VCC-)
/A0: J9.12, R53.1, U1.1 (A0), U3.43 (PB6)
/A1: J9.13, R54.1, U1.16 (A1), U3.44 (PB7)
/A2: J9.14, R55.1, U1.15 (A2), U3.46 (PB9)
/B0: J9.9, R50.1, U2.1 (A0), U3.17 (PB1)
/B1: J9.10, R51.1, U2.16 (A1), U3.41 (PB4)
/B2: J9.11, R52.1, U2.15 (A2), U3.42 (PB5)
/D+: J9.16, SW4.2 (B), U3.34 (PA12)
/D-: J9.15, SW5.2 (B), U3.33 (PA11)
/DAC1: J9.7, R19.1, U3.12 (PA4)
/DAC2: J9.8, R20.1, U3.13 (PA5)
/EOP+: J8.12, probopamp1.12 (+IND)
/EOP-: J8.13, probopamp1.13 (-IND)
/EOP_OUT: J8.14, probopamp1.14 (OUTD)
/OP4_IN+: C24.1, R21.2, probopamp1.10 (+INC)
/OP4_OUT: C23.2, J9.2, U3.29 (PB15), probopamp1.8 (OUTC), probopamp1.9 (-INC)
/PA0_ADC_IN1: C29.2, J9.1, U3.8 (PA0), U3.18 (PB2)
/PA1_OP1+: C28.1, R43.2, U3.9 (PA1)
/PA2_OP1_OUT: C27.2, R44.1, U3.10 (PA2)
/PA3_OP1-: U3.11 (PA3)
/PA6_OP2_OUT: C25.2, R15.1, U3.14 (PA6)
/PA7: J8.8, U3.15 (PA7)
/PA8: J8.9, U3.30 (PA8)
/PA9: J8.10, U3.31 (PA9)
/PA10: J8.11, U3.32 (PA10)
/PA13_SWDIO: J1.4, U3.37 (PA13)
/PA14_SCLK: J1.3, U3.38 (PA14)
/PA15_TM2_1: U3.39 (PA15)
/PB0_OP2+: C26.1, R41.2, U3.16 (PB0)
/PB3_TM2_1: J9.3, R4.1
/PB3_TM2_2: J9.4, R5.1, U3.40 (PB3)
/PB3_TM2_3: J9.5, R8.1
/PB3_TM2_4: J9.6, R11.1
/PB8: J8.15, R48.2, U3.45 (PB8)
/PB10_TM2_3: U3.22 (PB10)
/PB11_TM2_4: U3.25 (PB11)
/PB12: J8.6, U3.26 (PB12)
/PB13_OP3+: C30.1, R45.2, U3.27 (PB13)
/PB14: J8.7, U3.28 (PB14)
/PC13: J8.3, U3.2 (PC13)
/PC14: J8.4, U3.3 (PC14)
/PC15: J8.5, U3.4 (PC15)
/PF0: J8.1, U3.5 (PF0)
/PF1: J8.2, U3.6 (PF1)
/PG10_NRST: J1.2, J8.16, R56.2, U3.7 (PG10)
/S0: C22.1, J9.18, R16.2, R22.1, U1.8 (D), probopamp1.2 (-INA)
/S1: R22.2, R23.1, U1.4 (S1)
/S1B: C20.1, J9.17, R14.2, R30.1, probopamp1.6 (-INB)
/S2: R23.2, R24.1, U1.5 (S2)
/S2B: R30.2, R31.1, U2.4 (S1)
/S3: R24.2, R25.1, U1.6 (S3)
/S3B: R31.2, R32.1, U2.5 (S2)
/S4: R25.2, R26.1, U1.7 (S4)
/S4B: R32.2, R33.1, U2.6 (S3)
/S5: R26.2, R27.1, U1.12 (S5)
/S5B: R33.2, R34.1, U2.7 (S4)
/S6: R27.2, R28.1, U1.11 (S6)
/S6B: R34.2, R35.1, U2.12 (S5)
/S7: R28.2, R29.1, U1.10 (S7)
/S7B: R35.2, R36.1, U2.11 (S6)
/S8B: R36.2, R37.1, U2.10 (S7)
/SelSupp: SW2.2 (B), U1.13 (VDD), U2.13 (VDD)
/funcout1: J4.1 (In), R18.2, funcopamp1.1 (1OUT)
/funcout2: J5.1 (In), R17.2, funcopamp1.7 (2OUT)
/opout1: C22.2, R42.1, probopamp1.1 (OUTA)
/opout2: C20.2, R40.1, U2.8 (D), probopamp1.7 (OUTB)
/probA: J3.1 (In), R38.1
/probA1: D1.2, R16.1, R38.2
/probB: J2.1 (In), R39.1
/probB1: D2.2, R14.1, R39.2
/pwmopout3: C15.1, R10.2, pwmoppamp1.12 (IN4+)
/pwmopout4: C18.1, R13.2, pwmoppamp1.10 (IN3+)
/pwmout1: C10.2, C36.2, probopamp1.3 (+INA), pwmoppamp1.1 (OUT1), pwmoppamp1.2 (IN1-)
/pwmout2: C13.2, C37.2, probopamp1.5 (+INB), pwmoppamp1.6 (IN2-), pwmoppamp1.7 (OUT2)
/pwmout3: C16.2, C38.2, funcopamp1.3 (1IN+), pwmoppamp1.8 (OUT3), pwmoppamp1.9 (IN3-)
/pwmout4: C19.2, C39.2, funcopamp1.6 (2IN+), pwmoppamp1.13 (IN4-), pwmoppamp1.14 (OUT4)
GND: C1.2, C2.2, C3.1, C4.2, C5.2, C6.2, C7.2, C8.2, C9.2, C11.2, C12.2, C14.2, C15.2, C17.2, C18.2, C21.2, C24.2, C26.2, C28.2, C30.2, C31.2, C32.2, C33.2, C34.2, C35.2, C40.2, C41.2, C42.2, C44.2, D1.1, D2.1, D3.1 (K), D4.1 (K), D5.1 (K), D6.1 (K), D7.1 (K), D8.1 (K), D9.1 (K), J1.5, J2.2 (Ext), J3.2 (Ext), J4.2 (Ext), J5.2 (Ext), J7.4 (GND1), J7.8 (GND2), J8.20, R1.1, R46.2, R48.1, U1.3 (VSS), U1.14 (GND), U2.3 (VSS), U2.14 (GND), U3.19 (VSSA), U3.23 (VSS), U3.35 (VSS), U3.47 (VSS), anlgLDO1.2 (GND), dcdciso1.1 (-VIN), dcdciso1.4 (+VOUT), digildo1.1 (ADJ/GND), probopamp1.11 (V-), pwmoppamp1.11 (V-)
unnamed: C8.1, R3.1, R4.2
unnamed: C10.1, C36.1, R3.2, R47.1
unnamed: C11.1, R5.2, R6.1
unnamed: C13.1, C37.1, R6.2, R7.1
unnamed: C14.1, R8.2, R9.1
unnamed: C16.1, C38.1, R9.2, R10.1
unnamed: C17.1, R11.2, R12.1
unnamed: C19.1, C39.1, R12.2, R13.1
unnamed: C23.1, R15.2, R21.1
unnamed: C25.1, R40.2, R41.1
unnamed: C27.1, R42.2, R43.1
unnamed: C29.1, R44.2, R45.1
unnamed: D3.2 (A), R49.2
unnamed: D4.2 (A), R50.2
unnamed: D5.2 (A), R51.2
unnamed: D6.2 (A), R52.2
unnamed: D7.2 (A), R53.2
unnamed: D8.2 (A), R54.2
unnamed: D9.2 (A), R55.2
unnamed: J7.3 (D1+), SW4.3 (C)
unnamed: J7.2 (D1-), SW5.3 (C)
unnamed: J7.7 (D2+), SW4.1 (A)
unnamed: J7.6 (D2-), SW5.1 (A)
unnamed: C35.1, J7.SH (Shield), R46.1
unnamed: J7.1 (VBUS1), SW3.3 (C)
unnamed: J7.5 (VBUS2), SW3.1 (A)
unnamed: SW1.2 (B), SW3.2 (B)
unnamed: R29.2, U1.9 (S8)
unnamed: R37.2, U2.9 (S8)
unnamed: C2.1, L1.2, dcdciso1.2 (+VIN)
unnamed: R18.1, R19.2, funcopamp1.2 (1IN-)
unnamed: R17.1, R20.2, funcopamp1.5 (2IN-)
unnamed: C9.1, R47.2, pwmoppamp1.3 (IN1+)
unnamed: C12.1, R7.2, pwmoppamp1.5 (IN2+)

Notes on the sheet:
Attenuator network to OPamp conn
SELECT PIN MCU & ANALOG MUX CONN
ANTI ALIASING TO INTERNAL ADC CONN
DAC out from mcu & DAC in to OPamp conn
This stage contains conn. to ST-Link
PWM inputs to OPamps & Timers output from mcu conn
D+ AND D- CONN

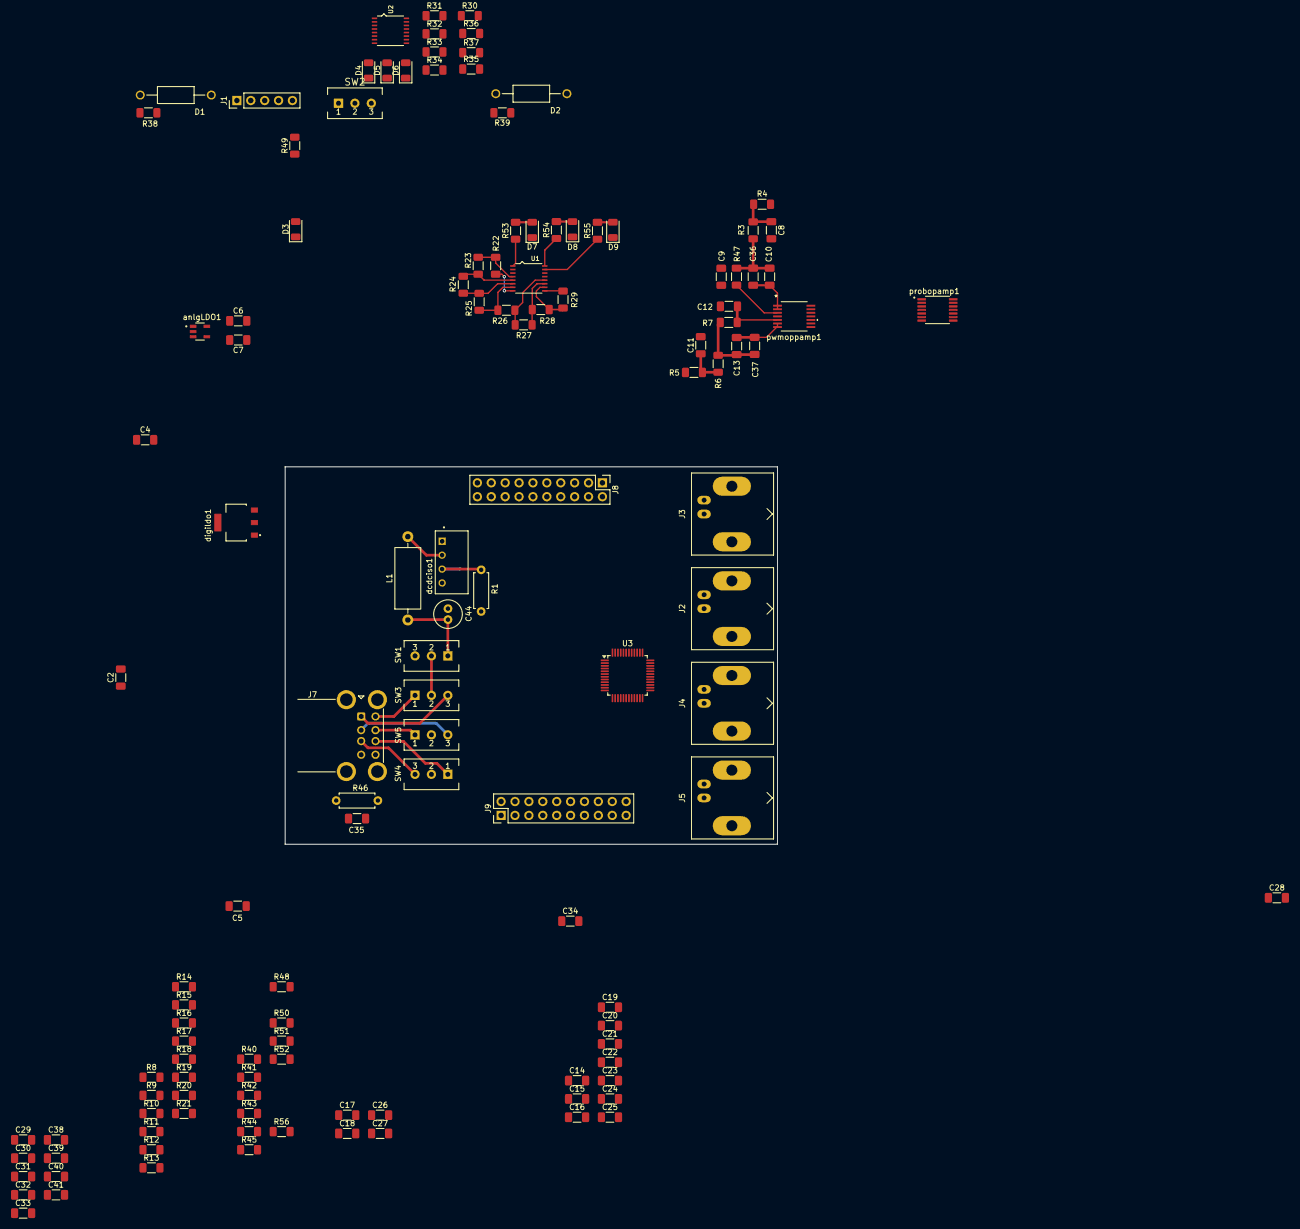
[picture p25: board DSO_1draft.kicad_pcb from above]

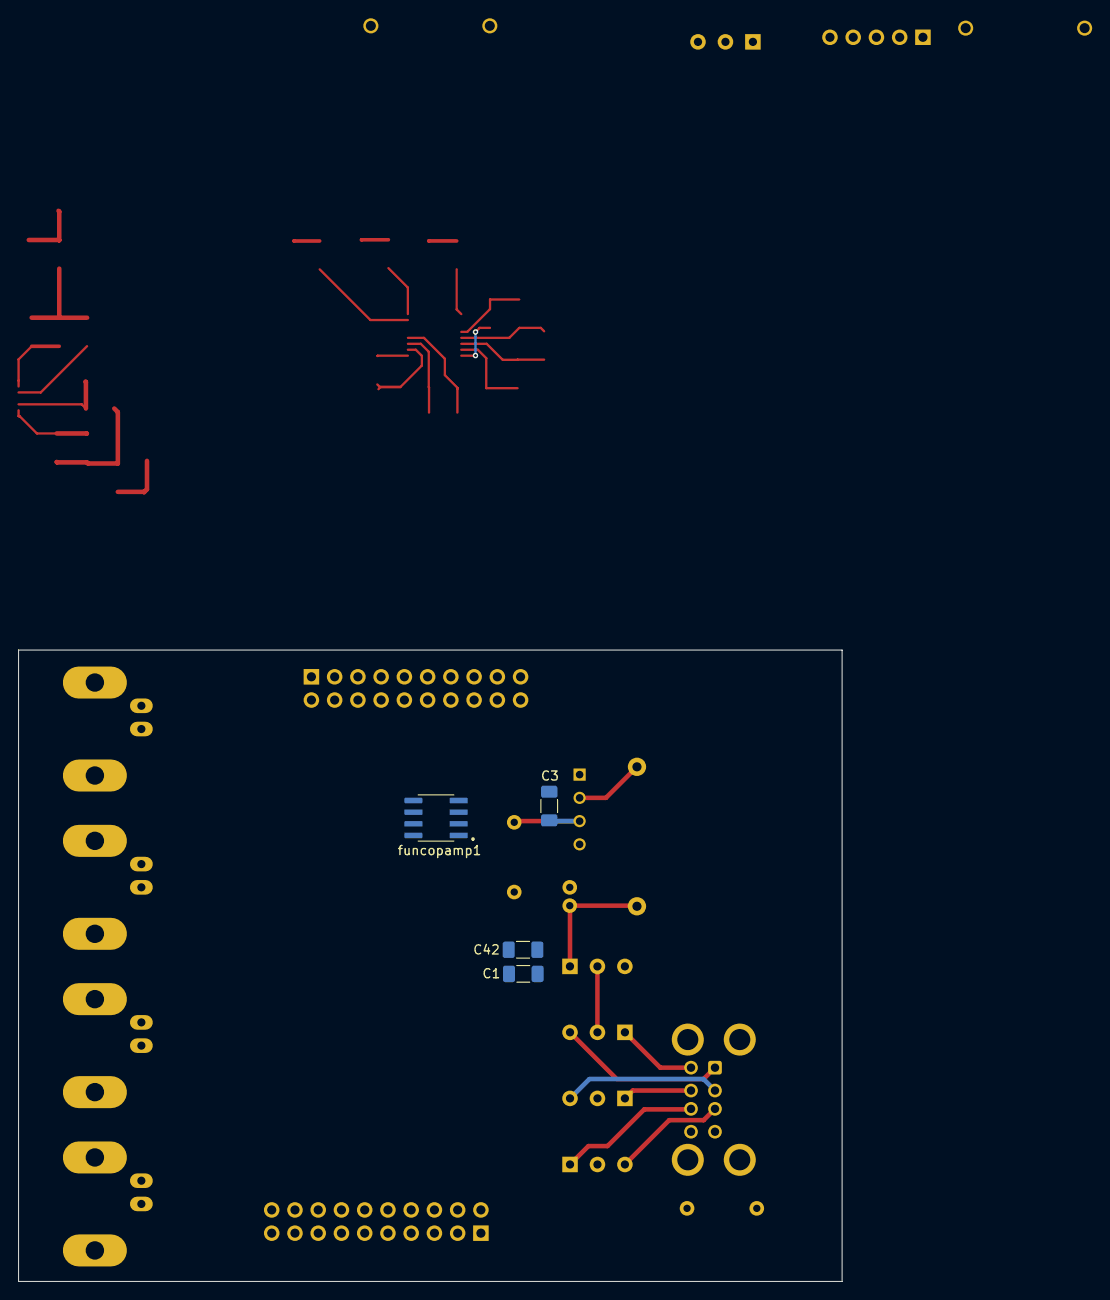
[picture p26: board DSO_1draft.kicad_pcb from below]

Board: 2 copper layers, 90.0 x 69.0 mm, 130 parts (4 on the bottom side), 110 nets.

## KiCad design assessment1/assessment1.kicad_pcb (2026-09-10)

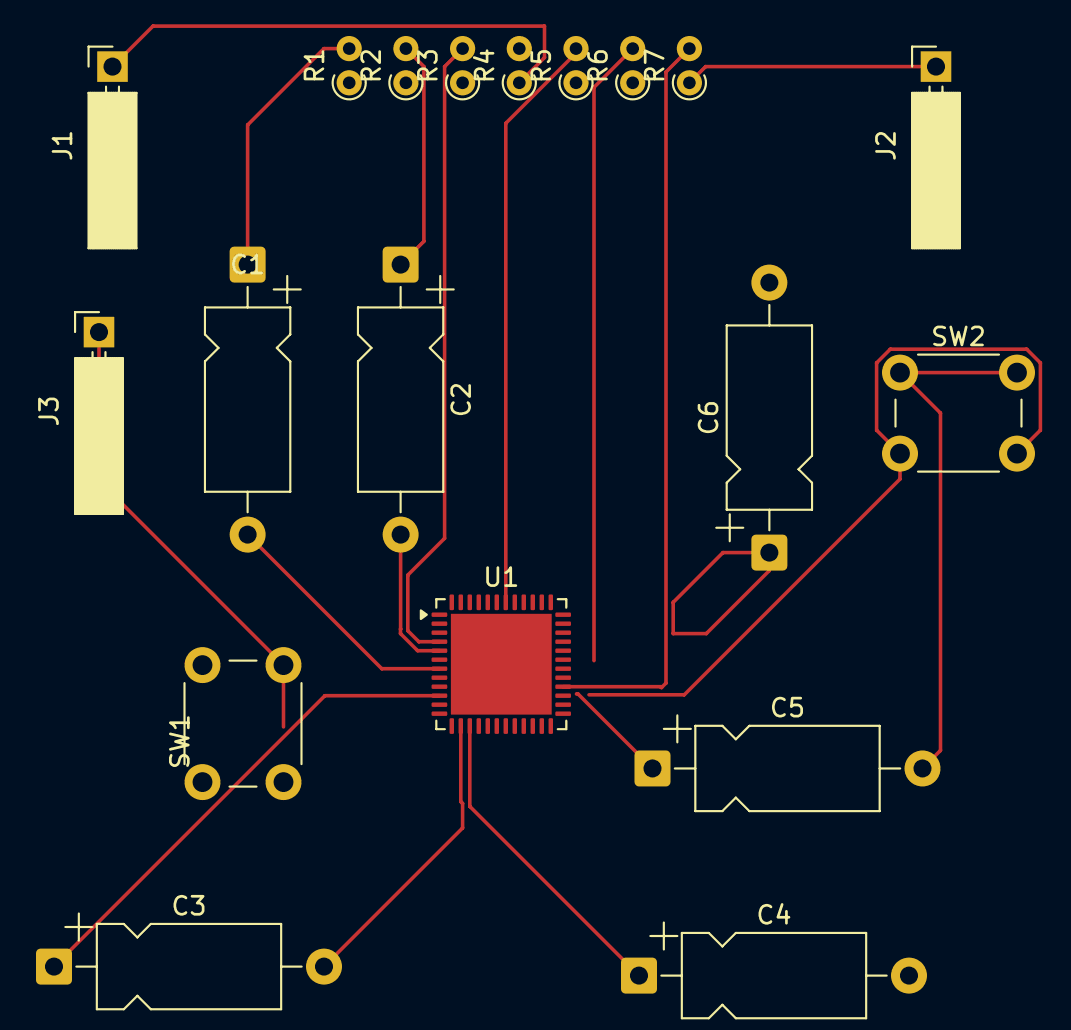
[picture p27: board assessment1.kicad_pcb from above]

Board: 2 copper layers, 19 parts (0 on the bottom side), 20 nets.

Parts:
C1, C2, C3, C4, C5, C6: C; CP_Axial_L10.0mm_D4.5mm_P15.00mm_Horizontal
J1, J2, J3: Conn_01x04_Socket; PinSocket_1x01_P2.54mm_Horizontal
R1, R2, R3, R4, R5, R6, R7: R; R_Axial_DIN0204_L3.6mm_D1.6mm_P1.90mm_Vertical
SW1, SW2: SW_Push_Dual; SW_PUSH_6mm
U1: STM32F401CBUx; QFN-48-1EP_7x7mm_P0.5mm_EP5.6x5.6mm

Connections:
unnamed: C1.1, R1.2
unnamed: C2.1, R2.2
unnamed: C5.2, SW2.1
unnamed: J1.1 (Pin_1_1), R4.1
unnamed: J2.1 (Pin_1_1), R7.1
unnamed: J3.1 (Pin_1_1), SW1.2
unnamed: C1.2, U1.7 (NRST)
unnamed: C3.1, U1.10 (PA0)
unnamed: SW1.1, U1.11 (PA1)
unnamed: C3.2, U1.14 (PA4)
unnamed: C4.1, U1.15 (PA5)
unnamed: C5.1, U1.31 (PA10)
unnamed: SW2.2, U1.34 (PA13)
unnamed: C6.1, U1.38 (PA15)
unnamed: R4.2, U1.20 (PB2)
unnamed: R5.2, U1.42 (PB6)
unnamed: R6.2, U1.21 (PB10)
unnamed: R7.2, U1.28 (PB15)
unnamed: R3.2, U1.4 (PC15)
unnamed: C2.2, U1.5 (PH0)

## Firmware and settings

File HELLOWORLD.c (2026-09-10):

#include <stdint.h>

// Simple STM32F103C8T6 test code for Wokwi addon in VS Code.
// Uses the popular STM32 "Blue Pill" board with a 72 MHz system clock.

#define RCC_APB2ENR   (*(volatile uint32_t *)0x40021018)
#define RCC_APB2ENR_IOPCEN (1 << 4)

#define GPIOC_CRH     (*(volatile uint32_t *)0x40011004)
#define GPIOC_ODR     (*(volatile uint32_t *)0x4001100C)

static void delay(volatile uint32_t count)
{
    while (count--) {
        __asm__("nop");
    }
}

int main(void)
{
    // Enable GPIOC peripheral clock
    RCC_APB2ENR |= RCC_APB2ENR_IOPCEN;

    // Configure PC13 as general purpose push-pull output, max speed 2 MHz.
    GPIOC_CRH &= ~(0xF << ((13 - 8) * 4));
    GPIOC_CRH |=  (0x2 << ((13 - 8) * 4));

    while (1) {
        // Toggle onboard LED on PC13
        GPIOC_ODR ^= (1 << 13);
        delay(3000000);
    }

    return 0;
}

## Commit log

2026-09-10 adding the updated files
    [ADG708BRUZ.step, AMS1117-3.3.step, DIP850W50P254L2000H510Q16N.PcbLib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]
2026-09-10 Add initial KiCad schematics and PCB drafts for assessment 1
    [DSO_1draft.kicad_pcb, DSO_1draft.kicad_sch, assessment1.kicad_pcb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]
2026-09-17 updated schematics
    [DSO_1draft.kicad_sch]
2026-09-17 added switch, no use now
2026-09-18 changed name
    [ADG708BRUZ.step, AMS1117-3.3.step, DIP850W50P254L2000H510Q16N.PcbLib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]
2026-09-18 some footprints assigned
    [DSO_1draft.kicad_sch]
2026-09-18 Update README with schematics PDF link
    Added link to full schematics PDF for reference.
2026-09-18 Update README formatting for schematics section
2026-09-18 added BOM from kicad
    [DSO_1draft.csv]
2026-09-18 Update link format for DSO schematics in README
2026-09-18 coloured carted items
    [DSO_1draft.csv]
2026-09-18 upadted to add stacked USB
    [DSO_1draft.kicad_sch]
2026-09-18 added robu BOM (incomplete)
2026-09-18 Revise ±5V supply generation description
    Updated description for the ±5V supply generation section in README.
2026-09-20 added AI BOM
    [DSO_1draft2_with_robu_links.csv, DSO_1draft2_with_robu_links_resistors_v2.csv]
2026-09-20 added slide switch info
2026-09-20 added offsetgen circuit
2026-09-20 modifid circuit according to parts avavailable
    [DSO_1draft.kicad_pcb, DSO_1draft.kicad_sch, DSO_1draft2.csv]
2026-09-20 added final BOM(excluding shrinivas R
2026-09-20 updated AI suggested BOM
    [DSO_1draft2_with_robu_links_resistors_v2.csv]
2026-09-20 modified circuit A/C to new BOM
    [DSO_1draft.kicad_sch]
2026-09-20 updated layout
    [DSO_1draft.kicad_pcb]
2026-09-23 added switch for usb_stack
    [DSO_1draft.kicad_pcb, DSO_1draft.kicad_sch]
2026-09-27 added gpt suggestion
    [DSO_1draft.kicad_pcb, DSO_1draft.kicad_sch]
2026-09-27 placed some components
    [DSO_1draft.kicad_pcb]
2026-09-28 modified layout placement
    [DSO_1draft.kicad_pcb]
2026-09-30 added table for local op
    [DSO_1draft.kicad_pcb]
2026-09-30 updated pcb
2026-10-01 Add protoflow KiCad changes
    [DSO_1draft.csv, DSO_1draft.kicad_pcb, DSO_1draft.kicad_sch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]
